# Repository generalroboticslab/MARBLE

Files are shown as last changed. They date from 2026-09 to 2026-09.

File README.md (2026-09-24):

<div align="center">

# MARBLE

**Omnidirectional Amphibious Locomotion via Internal Mass Actuation**

[Niko Weaver](https://github.com/NikoWeaver)\*,
[Boxi Xia](https://boxixia.github.io/)\*,
[Li-Yu Lo](https://pattylo.github.io/)\*,
[Yuhao Huang](https://hyh2001.github.io/),
[Boyuan Chen](https://boyuanchen.com)

\* equal contribution

General Robotics Lab, Duke University

**[Paper (arXiv)](https://arxiv.org/abs/2609.27358)** &middot;
**[Project page](https://generalroboticslab.com/MARBLE)** &middot;
**[Operations runbook](docs/OPERATIONS.md)** &middot;
**[Setup](docs/SETUP.md)** &middot;
**[Policies](policies/README.md)**





</div>

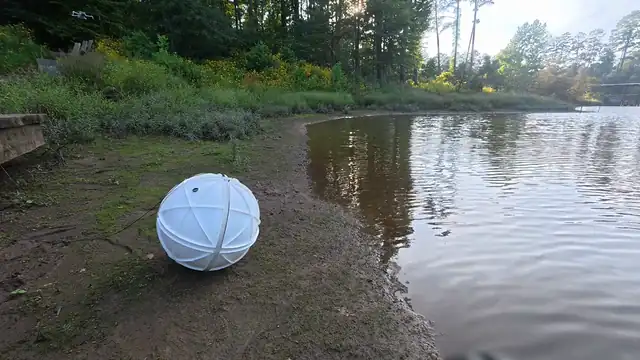
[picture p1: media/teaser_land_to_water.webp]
MARBLE rolling from land into water


<div align="center"><i>Land-to-water entry, real time.</i></div>

MARBLE is a sealed, omnidirectional amphibious robot. Three orthogonal sliders shift internal
masses to roll the spherical shell. The shell is the ground contact, buoyant hull and fin mount,
so one mechanism works on land and water with no reconfiguration.

This repository is the onboard control stack. An Orange Pi runs a 100 Hz loop that reads the
IMU, runs the geometric or learned controller, and sends slider targets over USB serial to a
XIAO nRF52840 CAN bridge driving three GL40 II motors. Bridge firmware, calibration tools and
checkpoints are included, and [`simulation/`](simulation/README.md) trains and replays the deployed
policies in MuJoCo. The code uses the working name `ballbot`.

> **Safety.** Restrain the robot for any first run, and keep a power cutoff within reach: no
> software stop cuts power. `X` latches the E-stop. The controller does not home by default; it
> arms at the pose the drivers report and steps the sliders to centre from it. During `--home`,
> only Ctrl+C stops it. See [safety](docs/OPERATIONS.md#safety),
> [homing](docs/OPERATIONS.md#homing) and [automatic stops](docs/OPERATIONS.md#automatic-stops).

## MARBLE on hardware

<table>
<tr>
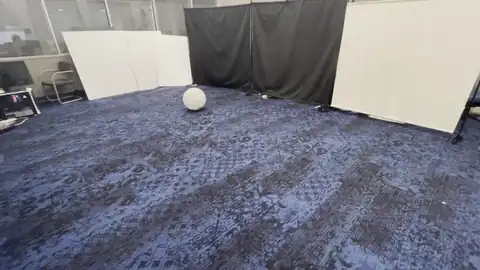
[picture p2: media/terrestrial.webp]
Terrestrial rolling
<td width="33%"></td>
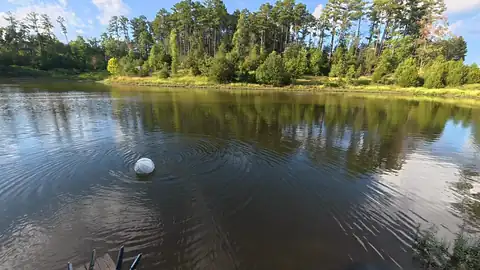
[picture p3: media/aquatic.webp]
Water-surface propulsion
<td width="33%"></td>
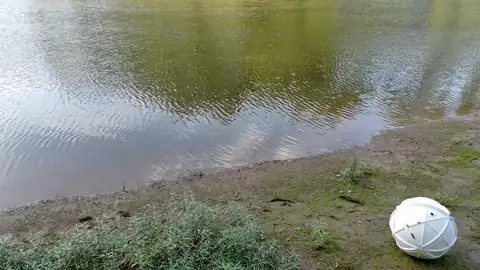
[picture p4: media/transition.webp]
Land-water transition
<td width="33%"></td>
</tr>
<tr>
<td><b>Terrestrial rolling, 1.5x speed.</b> The shell is the ground contact.</td>
<td><b>Water-surface propulsion, 2x speed.</b> Passive fins turn shell rotation into thrust.</td>
<td><b>Land-water transition, 3x speed.</b> One run, no change to the robot.</td>
</tr>
</table>

Planar trajectories of the paper's representative trials (Fig. 4). Colour is time, the circle
marks the start and the cross the end.

<table>
<tr>
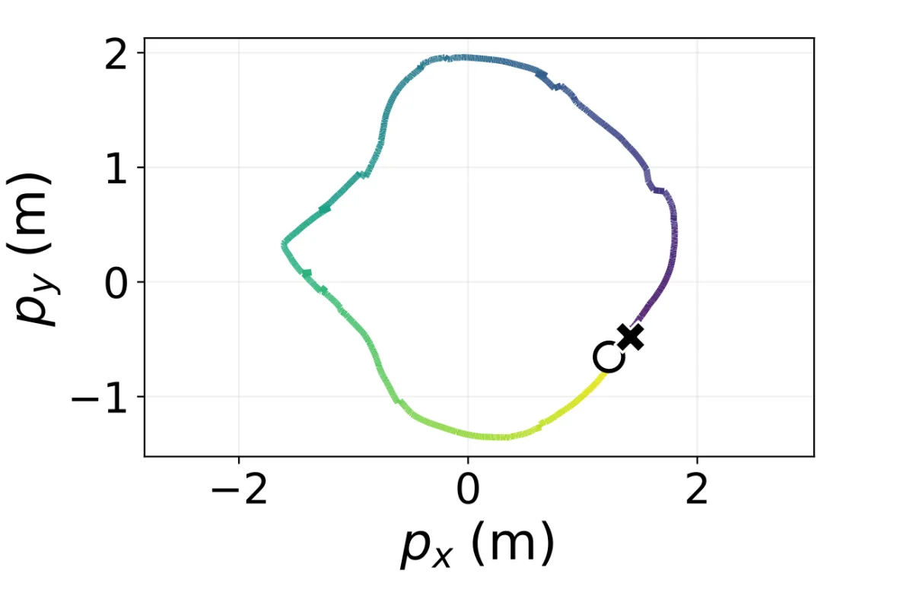
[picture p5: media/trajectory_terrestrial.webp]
Terrestrial trajectory
<td width="33%"></td>
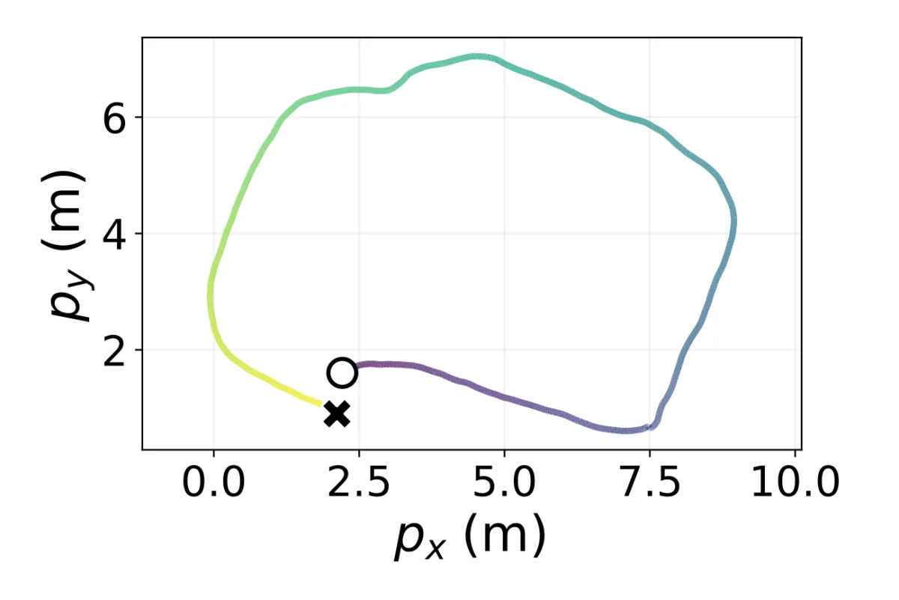
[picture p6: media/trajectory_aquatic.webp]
Aquatic trajectory
<td width="33%"></td>
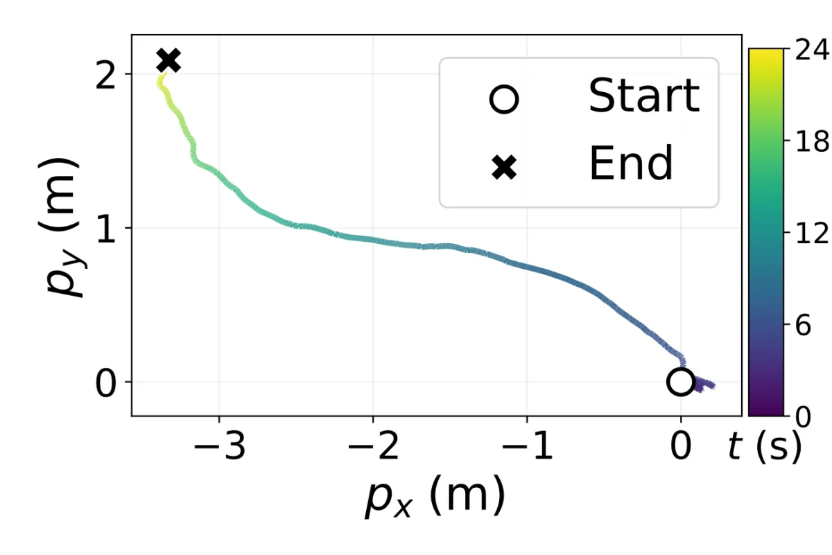
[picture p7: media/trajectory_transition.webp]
Transition trajectory
<td width="33%"></td>
</tr>
</table>

| | Terrestrial | Aquatic | Transition |
| --- | ---: | ---: | ---: |
| Distance | 10.60 m | 5.24 m | 5.21 m |
| Duration | 14.00 s | 14.00 s | 23.93 s |
| Mean speed | 0.745 ± 0.163 m/s | 0.375 ± 0.059 m/s | 0.215 ± 0.146 m/s |
| Max speed | 1.025 m/s | 0.488 m/s | 0.840 m/s |

The aquatic figures cover a 14 s window taken mid-trial, not the whole run.

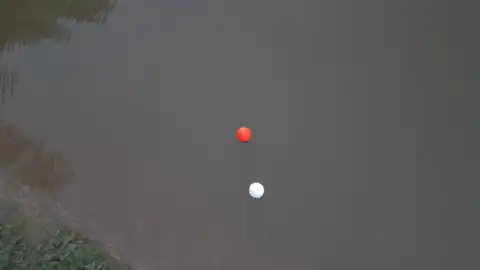
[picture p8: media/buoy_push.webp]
Obstacle interaction with a buoy, aerial view


**Obstacle interaction, aerial view, 4x speed.**

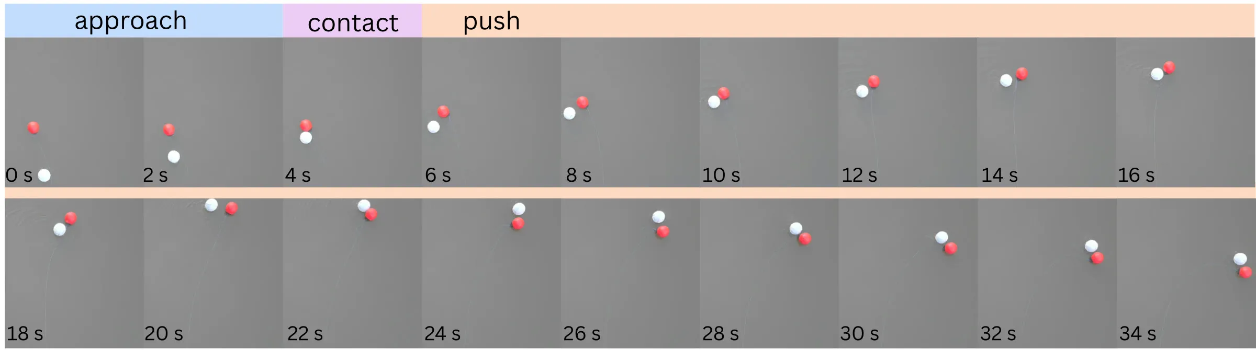
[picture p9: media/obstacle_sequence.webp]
Obstacle interaction time-lapse: approach, contact, push


Fig. 6 time-lapse, 0 to 34 s: approach, shell contact, continued pushing. MARBLE is white, the
buoy red.

## Locomotion and controllers

Locomotion principle

Moving the slider masses offsets the centre of gravity from the shell centre, and the moment
about the ground contact rolls the shell. The sliders rotate with the shell, so both controllers
read the IMU orientation every step.

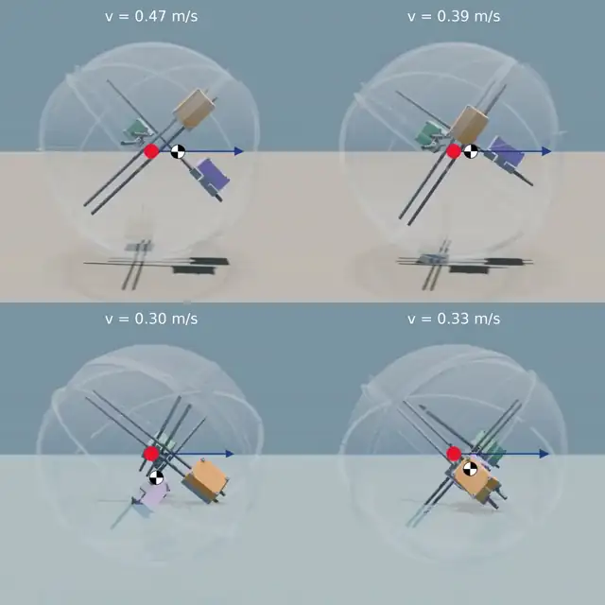
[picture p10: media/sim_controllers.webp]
Geometric and learned controllers in simulation, on ground and on water


MuJoCo rollouts at a commanded 0.5 m/s, real time. Rows: ground, water. Columns: geometric,
learned. The sliding masses have one colour per rail; the quartered circle is their centre of
gravity, the red dot the shell centre and the blue arrow the heading.

| Paper | Code | How to run it |
| --- | --- | --- |
| Geometric controller | `HeuristicPolicy` in [`src/ballbot_runtime.py`](src/ballbot_runtime.py) | `--policy heuristic` (`run.sh` option 4) |
| Learned controller | `TrainedPolicy` in [`src/ballbot_runtime.py`](src/ballbot_runtime.py) | `--policy trained --policy-path policies/<name>/policy_deployed.pt` (`run.sh` option 5) |

The geometric controller computes slider targets from the IMU orientation on every 100 Hz tick.
The learned controller is a 50 Hz TorchScript policy that maps the last three 23-value
observation frames to three slider targets.

The paper compares both controllers on hardware under operator velocity commands in every
direction (Fig. 5). Velocities come from differentiated camera trajectories, drawn from a
common origin with the same axes and colour scale in both panels.

<table>
<tr>
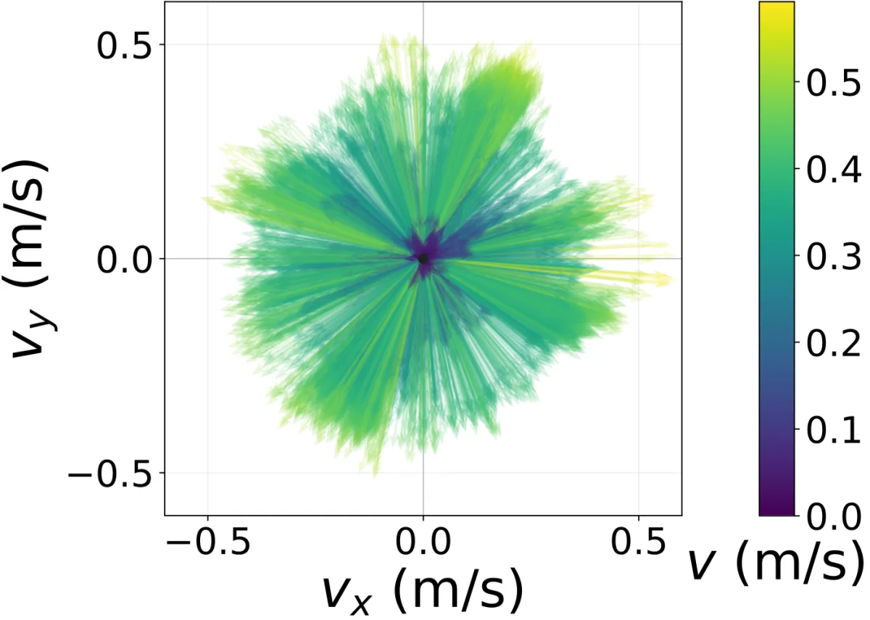
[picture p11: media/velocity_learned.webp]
Measured velocity vectors, learned controller
<td width="50%"></td>
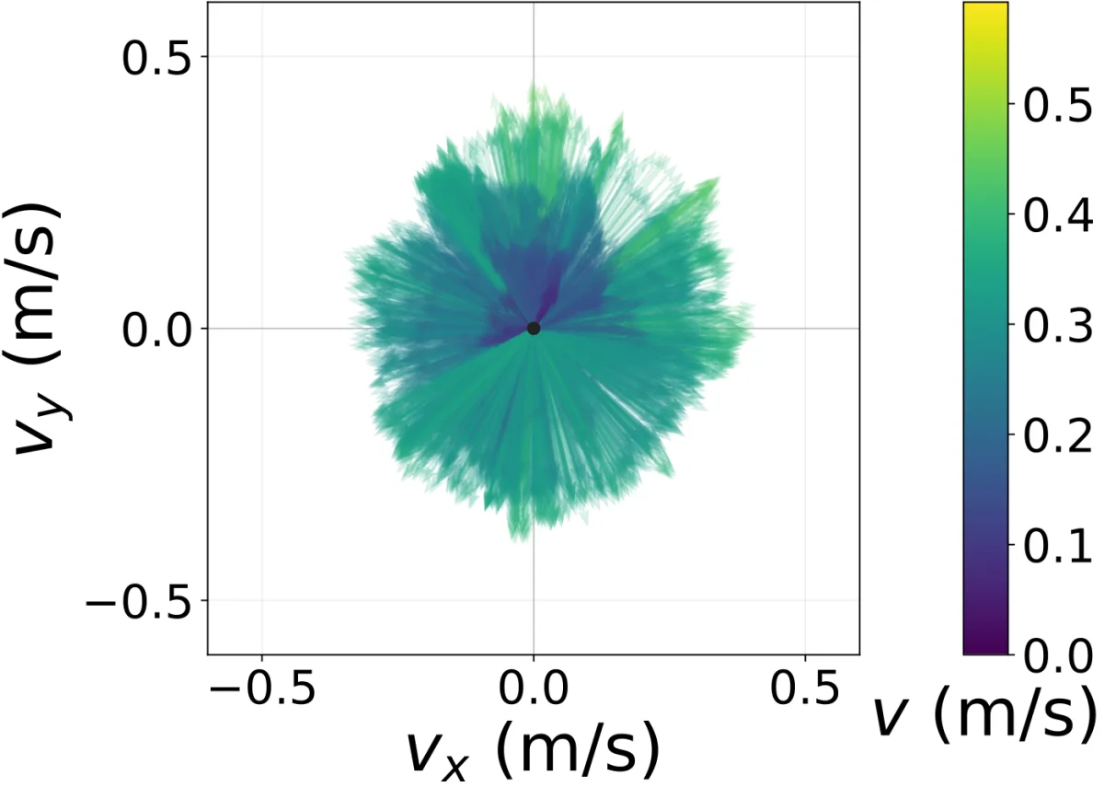
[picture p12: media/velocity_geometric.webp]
Measured velocity vectors, geometric controller
<td width="50%"></td>
</tr>
<tr>
<td><b>Learned controller.</b></td>
<td><b>Geometric controller.</b></td>
</tr>
</table>

| | Learned | Geometric |
| --- | ---: | ---: |
| Mean speed | 0.348 ± 0.114 m/s | 0.252 ± 0.088 m/s |
| Max speed | 0.592 m/s | 0.461 m/s |
| Distance covered | 94.10 m | 63.67 m |
| Duration | 270.37 s | 252.20 s |
| Velocity samples | 7,568 | 7,568 |

## Hardware

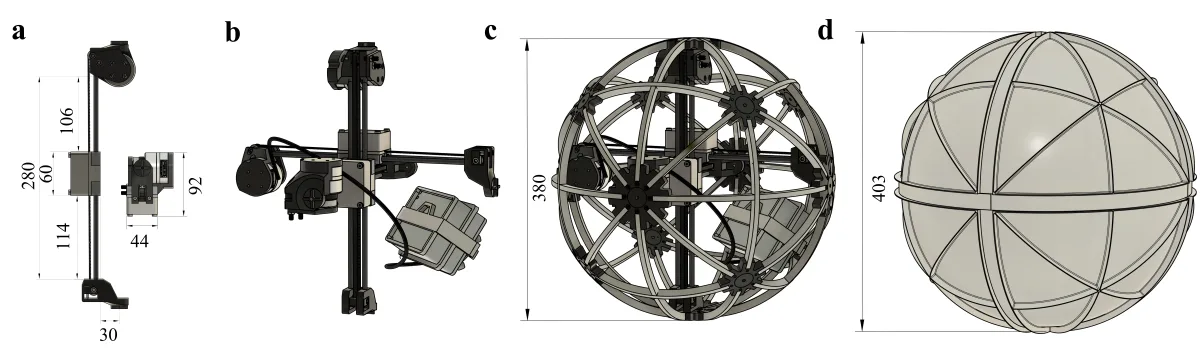
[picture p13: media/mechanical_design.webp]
MARBLE mechanical design


(a) Linear mass-slider module. (b) Three orthogonal sliders and the electronics capsule.
(c) Internal frame without the shell. (d) Complete robot with sealed shell and passive fins.
Dimensions in mm; the 403 mm in (d) is the 387 mm shell plus two 8 mm fins. The full
assembly is in [`cad/MarbleASM.step.zip`](cad/MarbleASM.step.zip) (zipped STEP).

| | |
| --- | --- |
| Outer diameter | 387 mm |
| Shell mass | 1.05 kg |
| Fin height | 8 mm |
| Mass sliders | 3 × 700 g |
| Slider stroke | 220 mm |
| Motors | 3 × CubeMars GL40 II, CAN IDs `0x08`, `0x07`, `0x06`, position-velocity mode |
| Motor bridge | Seeed XIAO nRF52840 Sense + MCP2515; USB serial 115200 baud, CAN 1 Mbit/s |
| IMU | SYD Dynamics TransducerM TM171, USB serial 4 Mbaud, EasyProfile protocol |
| Onboard computer | Orange Pi, aarch64 Linux, Python 3.12 |
| Control rate | 100 Hz; learned policy 50 Hz |
| Battery | 4S LiPo, 16 V |
| Operator input | Keyboard over `ssh -t` |

## System diagram

```
 keyboard over ssh -t                  TM171 IMU, USB serial 4 Mbaud
          |                                        |
          +-------------------+--------------------+
                              v
 Orange Pi   run.sh -> src/ballbot_terminal.py, 100 Hz  -------> logs/*.msgpack
                              |
             HeuristicPolicy (every tick) | TrainedPolicy (50 Hz)
                              | slider targets
             MotorJointMapper: config/calibration.json, clamp 10-195 mm
                              | motor positions
             GLMotorController
                              | USB serial, 115200 baud
 XIAO nRF52840 Sense -> MCP2515 (SPI)
                              | CAN, 1 Mbit/s
          GL40 II 0x08    GL40 II 0x07    GL40 II 0x06
```

## Quick start

```bash
# On the Orange Pi
micromamba create -n py312 python=3.12 -y && micromamba activate py312
export BALLBOT_PYTHON="$(command -v python)"
pip install torch --index-url https://download.pytorch.org/whl/cpu
VCPKG_ROOT=/path/to/vcpkg ./scripts/prepare_orangepi.sh

# Flash xiao_can/xiao_can_bridge/ with motor power off, then
python scripts/verify_xiao_firmware.py

# Over ssh -t, robot restrained: option 3, then option 4 (geometric) or 5 (learned)
./run.sh
```

[`docs/SETUP.md`](docs/SETUP.md) has the details; the committed calibration backup's motor IDs
were remapped, not measured, so run option 3 before the first control run. Read
[`docs/OPERATIONS.md`](docs/OPERATIONS.md) before driving, and always pass `--policy-path` when
launching `src/ballbot_terminal.py` directly: its default points at a retired checkpoint.

To play the deployed policies in simulation instead (desktop with an NVIDIA GPU):

```bash
micromamba create -n marble-sim python=3.12 -y && micromamba activate marble-sim
pip install -r simulation/requirements.txt
cd simulation
python mj_envs/run.py play --task BallbotVelComplexFlatDRLatency   # land
python mj_envs/run.py play --task BallbotVelRingCageComplexDR      # water
```

The shipped checkpoints in `policies/` load automatically; see
[`simulation/README.md`](simulation/README.md) for viewer keys, training and export.

## Documentation

| File | Covers |
| --- | --- |
| [`docs/OPERATIONS.md`](docs/OPERATIONS.md) | Running the robot: menu, keys, flags, automatic stops, logs |
| [`docs/SETUP.md`](docs/SETUP.md) | Install, build, serial ports, flashing, calibration |
| [`docs/validation.md`](docs/validation.md) | Bring-up checklist for a new or rebuilt robot |
| [`docs/DEVELOPING.md`](docs/DEVELOPING.md) | Code map, controller interfaces, observation layout, offline checks |
| [`docs/FLASH_XIAO.md`](docs/FLASH_XIAO.md) | Flashing the bridge firmware |
| [`policies/README.md`](policies/README.md) | Checkpoint catalogue |
| [`simulation/README.md`](simulation/README.md) | Training and playing the policies in simulation |
| [`hardware_bindings/README.md`](hardware_bindings/README.md) | IMU binding |
| [`PROVENANCE.md`](PROVENANCE.md) | Release sources, removed material, third-party code |

## Repository

```
run.sh               operator menu
src/                 control loop, controllers, motor mapping
xiao_can/            GL40 II driver and bridge firmware
hardware_bindings/   C++/nanobind IMU binding
scripts/             calibration, homing, bring-up, offline checks
config/              Python requirements, calibration backup
policies/            TorchScript checkpoints
simulation/          MuJoCo training and playback of the deployed policies
cad/                 STEP assembly of the robot (zipped)
docs/                runbook, setup, developer guide, checklist
media/               figures and clips in this README
CMakeLists.txt       IMU binding build
```

## Provenance and licence

This is a fresh-history release; [`PROVENANCE.md`](PROVENANCE.md) records its sources. The code
is licensed under Apache-2.0 ([`LICENSE`](LICENSE)). The EasyProfile SDK under
`hardware_bindings/imu/EasyProfile/` is BSD-2-Clause; see its
[`NOTICE.md`](hardware_bindings/imu/EasyProfile/NOTICE.md).

## Citation

```bibtex
@misc{weaver2026omnidirectionalamphibiouslocomotion,
      title={Omnidirectional Amphibious Locomotion via Internal Mass Actuation},
      author={Niko Weaver and Boxi Xia and Li-Yu Lo and Yuhao Huang and Boyuan Chen},
      year={2026},
      eprint={2609.27358},
      archivePrefix={arXiv},
      primaryClass={cs.RO},
      url={https://arxiv.org/abs/2609.27358},
}
```

## Acknowledgements

This work was conducted at the General Robotics Lab, Duke University. This work is supported by
DARPA FoundSci program under award HR00112490372, DARPA TIAMAT program under award
HR00112490419, ARO under award W911NF2410405, ARL STRONG program under awards W911NF2320182,
W911NF2220113, and W911NF242021.

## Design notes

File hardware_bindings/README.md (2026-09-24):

# hardware_bindings

The C++ driver for the SYD Dynamics TM171 IMU, exposed to Python through nanobind.

```python
from hardware_bindings.imu.py_imu import IMU
```

The motors do not use this package; they use
[`xiao_can/xiao_gl_motor.py`](../xiao_can/xiao_gl_motor.py).

## Contents

| Path | Contents |
|---|---|
| `imu/imu.hpp`, `imu/imu_nanobind.cpp` | The driver and its nanobind module, `imu_nanobind`. |
| `imu/py_imu.py` | The Python wrapper, `IMU`. Loads `imu_nanobind.abi3.so` from its own directory. |
| `imu/EasyProfile/` | The vendor's protocol SDK, BSD-2-Clause. Ship [`NOTICE.md`](imu/EasyProfile/NOTICE.md) with any binary build. |
| `common/publisher.py` | Socket publisher used by the live viewer. |
| `CMakeLists.txt`, `imu/CMakeLists.txt` | Build rules. |
| `pyproject.toml` | Packaging metadata for use from another project. |

## Building

Build from the repository root with
[`scripts/prepare_orangepi.sh`](../scripts/prepare_orangepi.sh) (see
[`docs/SETUP.md`](../docs/SETUP.md)). It writes `imu_nanobind.abi3.so` and a
copy of `libnanobind-abi3.so` into `imu/`. Before the build, importing
`py_imu` raises `FileNotFoundError` naming the missing `.so`.

The control stack needs no install step. From another project, build first,
then `pip install -e hardware_bindings` (editable, so `libnanobind-abi3.so` is
found).

## The `IMU` class

`IMU(port_name=None)` opens the port at 4,000,000 baud (autodetected when
`None`, see [`docs/SETUP.md`](../docs/SETUP.md#serial-ports)) and starts reading.

| Attribute | Meaning |
|---|---|
| `counter` | Increments with each parsed sample. If it stalls for 5 s, the terminal disables the motors and exits. |
| `rotation_matrix` | 3x3 sensor orientation in the IMU's world frame. |
| `ang_vel` | Body rate in the sensor frame, rad/s. |

The other properties are bound in [`imu/imu_nanobind.cpp`](imu/imu_nanobind.cpp).
`shutdown()` closes the port. `ImuState.from_device` converts the IMU readings
into the controllers' frame; see
[`docs/DEVELOPING.md`](../docs/DEVELOPING.md#units-and-frames).

## Live viewer

```bash
python hardware_bindings/imu/py_imu.py
```

Serves a 3D view with live plots on port 8080 (viser) and publishes each sample
as msgpack over UDP to `localhost:9870`. Needs the built extension plus `viser`,
`scipy`, `orjson` and `msgpack` (all in `config/requirements-robot.txt`).

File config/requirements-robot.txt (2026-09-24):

nanobind
numpy
pyserial
pyyaml
tqdm
msgpack  # run logs written by src/ballbot_terminal.py, read by scripts/analyze_policy_log.py
tyro  # command-line interface of src/ballbot_terminal.py
scipy  # scripts/calibrate_imu.py --viz and --capture-upright
viser  # live 3D view: scripts/calibrate_imu.py --viz (run.sh option 2)
mujoco  # scripts/policy_sim_check.py (offline check)
orjson  # hardware_bindings/common/publisher.py, used by the py_imu.py stand-alone viewer

# PyTorch is not listed: install a CPU build for your platform separately.
# Only trained policies need it (--policy trained, --preflight, policy_sim_check.py).

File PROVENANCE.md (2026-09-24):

# Provenance

This repository is a fresh-history public release, assembled from two internal
General Robotics Lab repositories by copying cleaned file trees. The internal
history is not published.

## Sources

| Directory here | Internal repository | Branch | Commit |
|---|---|---|---|
| everything except `hardware_bindings/`, `simulation/`, `media/` and `cad/` | ballbot_control | `CAN_rework` | `401d29a14e05e3287c25f97f9496d889925c85c2` |
| `hardware_bindings/` | hardware_bindings | `ballbot` | `06d9f5e581b3dbc43382254591f45bf441aef403` |
| `simulation/` | legged_env_v2 (training) | `master` | generated by its `scripts/make_marble_sim.py` |

The documentation, `LICENSE`, `CITATION.cff`, `.gitattributes`, this file and
the EasyProfile `NOTICE.md` are new. Kept files lost commented-out code and
unused functions; apart from the removals below, control behaviour is
unchanged.

`hardware_bindings/` inlines only the IMU extension of a private submodule
shared by several lab robots, with unused code (`FakeIMU`, a getter, the NNG
publisher classes) removed and the build files cut to match.
`imu/EasyProfile/` is byte-identical to the internal copy.

`cad/MarbleASM.step.zip` is the robot's CAD assembly as STEP. It
includes vendor models of purchased parts (GL40 II motors, the XIAO board and
its CAN breakout, electronics, fasteners); those keep their vendors' terms.

## Removed

| Removed | Reason |
|---|---|
| `deprecated/` | Superseded entry points and experiments |
| `gs_usb/` | Retired SocketCAN path, replaced by `xiao_can/` |
| `camera/` | Optional camera pipeline, not in this stack |
| `handoff.md`, `camera/handoff.md` | Internal notes |
| `visualization/` | Overhead-video trajectory tools and one run's data; not part of the control stack |
| `hardware_bindings/motor/`, `hardware_bindings/ft_servo/` | Drivers for another robot |
| `hardware_bindings/imu/test_dual_imu.py` | Two-IMU rig; MARBLE has one |
| `scripts/rehome_sliders.py`, `scripts/rehome_interactive.py` | Superseded by `scripts/rehome_auto.py` |
| `scripts/enable_motor_5_only.py` | One-off for retired motor IDs |
| `scripts/test_control_timing.py` | Tested a scheduler that no longer exists |
| `scripts/test_sine_log.py` | One-off bench script |
| `scripts/convert_gains.py` | Its default geometry was wrong |
| `xiao_can/xiao_can_bridge/XboxBluefruitClient.h` | Never compiled into the firmware |
| `src/xbox_controller.py` and `--xbox` | Xbox input dropped; the keyboard drives |
| `config/startupcommands.txt` | Stale copy of [`docs/SETUP.md`](docs/SETUP.md) |
| `docs/TRAINED_POLICY_GUIDE.md` | Stale; replaced by [`docs/DEVELOPING.md`](docs/DEVELOPING.md) |
| `policies/BallbotVelRingCageFlatDRLatency/meshes` | Symlink into the training asset tree |
| `.vscode/settings.json` | Editor settings, not source |
| `logs/` | Recorded runs (four msgpack logs and plots) |
| `.gitmodules` | Submodule pointer; source now inlined |

## Motor IDs

The release uses CAN IDs `0x08`, `0x07` and `0x06` (`MOTOR_IDS` in
`src/ballbot_runtime.py`), and the bridge firmware matches
([`docs/FLASH_XIAO.md`](docs/FLASH_XIAO.md)).

`config/calibration.robot-backup.json` was recorded on the old ID set (`0x03`,
`0x04`, `0x06`); its IDs were rewritten to `0x08`, `0x07`, `0x06` in
`JOINT_NAMES` order with the signs carried over, so it may not match a robot's
wiring. Calibrate before the first control run
([`docs/SETUP.md`](docs/SETUP.md#slider-calibration)).

## The shipped checkpoints

The six `policy_deployed.pt` archives are the internal copies with
TorchScript's `*.debug_pkl` entries (training-machine paths and source text)
removed. Weights and compiled code are byte-identical and outputs match; the
md5s in [`policies/README.md`](policies/README.md#checksums) differ from the
internal copies.

Each `robot.xml` references meshes from the training asset tree (STL, plus one
OBJ in four of them) and, in those four, `textures/carbon_fiber_plain_spec.png`.
These are not redistributed, so `robot.xml` does not compile in MuJoCo from
this repository. The runtime reads only `env_config.yaml`;
`scripts/policy_sim_check.py` needs the meshes and texture. The wire mesh is
referenced as `meshes/wire_1_Body1.stl`, which differs from its file name in
the training asset tree; rename that file to match.

## Third-party components

Only EasyProfile is redistributed; everything else is fetched at setup under
its own licence. Versions are unpinned except the two Arduino packages in
[`docs/FLASH_XIAO.md`](docs/FLASH_XIAO.md).

| Component | Use | Source | Licence |
|---|---|---|---|
| SYD Dynamics EasyProfile 1.1.9 (R) | IMU serial protocol; code adapted into `hardware_bindings/imu/imu.hpp` | `hardware_bindings/imu/EasyProfile/` | BSD-2-Clause; see [`NOTICE.md`](hardware_bindings/imu/EasyProfile/NOTICE.md) |
| nanobind | Python binding of the IMU driver | pip | BSD-3-Clause |
| Eigen3 | Linear algebra in the IMU driver | vcpkg | MPL-2.0 |
| CSerialPort (itas109) | Serial port in the IMU driver | vcpkg | LGPL-3.0 with a linking exception |
| fmt | Linked into the IMU extension | vcpkg | MIT |
| Seeed nRF52 Boards (`Seeeduino:nrf52`) | Board package for the XIAO bridge firmware | Seeed Arduino board index | LGPL-2.1-or-later; not redistributed |
| `mcp_canbus` (Longan Labs) | MCP2515 driver in the firmware | https://github.com/Longan-Labs/Arduino_CAN_BUS_MCP2515 | MIT |
| Python packages | Runtime, tools, offline checks | PyPI: `config/requirements-robot.txt` | Each its own |
| PyTorch | Running trained policies | Installed separately | BSD-3-Clause, plus bundled components |

## Media

`media/` holds figures and clips from the project page
(https://generalroboticslab.com/MARBLE), re-encoded as WebP.

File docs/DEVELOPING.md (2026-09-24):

# Developing

Run the examples from the repository root.

## Code map

| Path | Contents |
|---|---|
| `src/ballbot_runtime.py` | Constants, calibration, joint-to-motor mapper, IMU frame, both controllers, policy contract check. No hardware I/O; imports only `numpy` at load. |
| `src/ballbot_terminal.py` | `BallbotController`: 100 Hz loop, keyboard, arming, homing, safety, logging. Also the CLI. |
| `xiao_can/xiao_gl_motor.py` | `GLMotorController`: GL40 motors through the XIAO serial-to-CAN bridge. |
| `xiao_can/xiao_can_bridge/` | Bridge firmware. Host sends `S:<id>:<length>:<data>` (hex); bridge returns `R:` lines; `V` returns the version string. |
| `hardware_bindings/imu/py_imu.py` | `IMU` driver ([README](../hardware_bindings/README.md)). |
| `scripts/` | Calibration, bench tools, [offline checks](#offline-checks). |

## Units and frames

**Joints.** Every three-element array (observation, action, target) is in
`JOINT_NAMES` order: `base_link_Slider-5`, `base_link_Slider-6`,
`base_link_Slider-7`. A joint position is metres from the 114 mm idle position
(`IDLE_POSITION_MM`) on 220 mm of travel (`MAX_TRAVEL_MM`). Positive motion
moves the mass toward base −Z, +Y and −X respectively (`JOINT_POSITIVE_AXIS`).

**Motors.** Motor positions are radians, in `MOTOR_IDS` order `0x08`, `0x07`,
`0x06`. One turn is 100 mm (`MM_PER_TURN`). After homing, 0 rad is the 0 mm
hardstop. `MotorJointMapper` converts using `config/calibration.json`.

**Calibration file.** `schema_version` 2. Per joint: `motor_id` (8, 7 or 6,
each once), `encoder_sign` and `joint_to_travel_sign` (each ±1). The loader
rejects any other schema version and any mapping that does not cover every
joint and motor exactly once. The procedure is in
[`SETUP.md`](SETUP.md#slider-calibration).

**Orientation.** `ImuState` holds `rotation_world_base` (R_wb) and
`angular_velocity_world` (rad/s). `ImuState.from_device(imu)` computes
R_wb = R_ws R_bs^T and ω_world = R_ws ω_sensor, with R_bs the IMU mounting
rotation (`R_BASE_SENSOR`). It raises `ValueError` on non-finite or
non-orthonormal data.

**Command frame.** Commands are in world XY. `with_yaw_reference(yaw)` rotates
the world frame about +Z so command +X points at `yaw`, leaving roll and pitch
unchanged. The terminal sets it from `--yaw-offset-deg` and Q/E.

**Travel limits.**

| Stage | Limit |
|---|---|
| `HeuristicPolicy.act` | −0.104 to +0.096 m (`HEURISTIC_LOWER_M`, `HEURISTIC_UPPER_M`) |
| `TrainedPolicy.act_from_frame` | −0.114 to +0.106 m (`JOINT_LOWER_M`, `JOINT_UPPER_M`) |
| `MotorJointMapper`, every target | Joint clipped to −0.114/+0.106 m, then travel to 10–195 mm (`SAFE_MIN_TRAVEL_MM`, `SAFE_MAX_TRAVEL_MM`) |

Reach from the 114 mm centre is asymmetric (104 mm down, 81 mm up);
`joint_to_travel_sign` sets which side is short.

## Runtime API

### Geometric controller

```python
import sys
from pathlib import Path

import numpy as np

sys.path.insert(0, "src")
from ballbot_runtime import HeuristicPolicy, ImuState, MotorJointMapper, SliderCalibration

# The robot uses config/calibration.json; the backup runs on a fresh clone.
cal = SliderCalibration.load(Path("config/calibration.robot-backup.json"))
mapper = MotorJointMapper(cal)

policy = HeuristicPolicy()

# Upright and at rest. On the robot this comes from ImuState.from_device(imu).
imu_state = ImuState(rotation_world_base=np.eye(3), angular_velocity_world=np.zeros(3))

direction_xy = np.array([1.0, 0.0])   # toward +X of the command frame
magnitude = 0.5                       # 0 to 1

joint_targets_m = policy.act(direction_xy, magnitude, imu_state, np.zeros(3), np.zeros(3))
motor_targets_rad = mapper.motor_targets_from_joint_position(joint_targets_m)
```

`HeuristicPolicy.act()` places a point 1.5 × magnitude m out along the
direction and sends each slider to the closest point on its rail; the example
returns `[0, 0, -0.104]`.

### Learned policy

```python
import sys
from pathlib import Path

import numpy as np

sys.path.insert(0, "src")
from ballbot_runtime import ImuState, TrainedPolicy

policy = TrainedPolicy(Path("policies/BallbotVelComplexFlatDRLatency/policy_deployed.pt"))

imu_state = ImuState(np.eye(3), np.zeros(3))
joint_pos = np.zeros(3, dtype=np.float32)    # m, from MotorJointMapper.joint_state_from_motors
joint_vel = np.zeros(3, dtype=np.float32)    # m/s
last_action = np.zeros(3, dtype=np.float32)

policy.reset()
for _ in range(5):                           # one call per 50 Hz policy step
    frame = TrainedPolicy.build_frame(
        np.array([0.3, 0.0]),                # commanded velocity in the command frame, m/s
        imu_state, joint_pos, joint_vel, last_action,
    )
    joint_targets_m, last_action = policy.act_from_frame(frame)
```

`TrainedPolicy(policy_path, action_scale=1.0, policy_hz=POLICY_HZ, strict=True)`
loads the model on the CPU, checks the [`env_config.yaml`](#env_configyaml-contract)
beside it, and confirms a finite `(1, 3)` output for a zero input. It raises on
any failure.

- `build_frame(command_world_xy, imu_state, joint_pos, joint_vel, last_action)`
  (static) returns the 23-element [frame](#observation-frame).
- `act_from_frame(frame)` appends to the three-frame history and returns
  `(joint_targets_m, action)`. Pass `action` back as `last_action`.
- `reset(frame=None)` fills the history with copies of `frame`, or zeros.
- `set_action_scale(scale)` sets the runtime scale, clipped to [0, 1].

Call `act_from_frame` once every 20 ms (`POLICY_HZ` = 50). Always pass
`policy_path`: `DEFAULT_POLICY_PATH` names a retired checkpoint
([`OPERATIONS.md`](OPERATIONS.md#learned-policy)).

### Motors

The terminal opens the bridge like this (run with `PYTHONPATH=src:xiao_can`):

```python
from ballbot_runtime import MOTOR_IDS
from xiao_gl_motor import GL40, GL_MODE_POS_VEL, GLMotorController

motor = GLMotorController(
    [[motor_id, "xiao", GL40] for motor_id in MOTOR_IDS],
    control_mode=GL_MODE_POS_VEL,
    default_vel_limit=30.0,   # rad/s; the terminal passes --vel-limit
    port_name=None,           # autodetect; the terminal passes --motor-port
)
```

Arrays are in `MOTOR_IDS` order: write `mech_pos_ref`/`mech_vel_ref`, read
`mech_pos`, `mech_vel`, temperatures, `error_code` and `last_feedback_time`.
`motion_control_once()` sends one command to every motor.

The constructor raises `RuntimeError` unless the bridge reports
`BALLBOT_XIAO_BRIDGE_V3` ([`FLASH_XIAO.md`](FLASH_XIAO.md)) and leaves the
motors disabled. Feedback streams only after `enable()`; follow
`BallbotController.arm()` for a safe start.

`ballbot_runtime.py` has no safety logic. A program that drives the motors
itself gets none of the terminal's
[automatic stops](OPERATIONS.md#automatic-stops) or learned-policy limits.

## Adding a controller

A controller needs one method, called positionally:
`act(direction_world_xy, magnitude, imu_state, joint_pos, joint_vel)`,
returning (3,) float32 slider targets in metres from centre. Inputs are in the
command frame, and `direction_world_xy` is a unit vector.

There is no plug-in hook: replace `self.heuristic = HeuristicPolicy()` in
`BallbotController.__init__` and launch with `--policy heuristic`. The terminal
calls `act()` every 100 Hz tick while a movement command is active and centres
the sliders otherwise. `magnitude` starts at `--heuristic-magnitude`; N/M move
it in 0.1 steps within [0.01, 10.0], so clip it yourself. With smoothing off
(the default), targets go from the mapper clip straight to the drives.

## Exporting a learned policy

The runtime accepts any TorchScript module that meets this contract:

| | |
|---|---|
| Input | float32 `(1, 3, 23)`: three [frames](#observation-frame), oldest first |
| Output | `(1, 3)`, in `JOINT_NAMES` order |
| Output meaning | Clipped to [−1, 1], × 0.106 m (`ACTION_SCALE_M`) × runtime action scale (`--action-scale`, default 1.0), then clipped to −0.114/+0.106 m. An absolute target from centre, not an increment. |
| Rate | 50 Hz (`POLICY_HZ`) |
| Device | CPU: `torch.jit.load(path, map_location="cpu")` |

Save the traced or scripted actor as `policy_deployed.pt`:

```python
import torch

model.eval()
example = torch.zeros((1, 3, 23), dtype=torch.float32)   # (batch, history, frame)
with torch.no_grad():
    traced = torch.jit.trace(model, example)
traced.save("policies/MyPolicy/policy_deployed.pt")
```

Put the `env_config.yaml` exported by training beside it
([contract](#env_configyaml-contract)); a hand-written one checks nothing.
Without `env_config.yaml` the runtime prints a `NOTE` and runs only the shape
check, which cannot catch a wrong action scale or a reordered frame.

Check it, then run it:

```bash
python src/ballbot_terminal.py --preflight --policy-path policies/MyPolicy/policy_deployed.pt
python src/ballbot_terminal.py --policy trained --policy-path policies/MyPolicy/policy_deployed.pt
```

`./run.sh` lists the new folder in options 5 and 6 automatically.

## Observation frame

`TrainedPolicy.build_frame` packs each frame in this order. Terms are named as
in `env_config.yaml`.

| Index | Term | Source | Units |
|---|---|---|---|
| 0-2 | `angular_velocity` | `imu_state.angular_velocity_world` | rad/s, command frame |
| 3-4 | `commands_xy` | commanded velocity; in the terminal, unit direction × `--speed` | m/s, command frame |
| 5-7 | `dofPosition` | `joint_pos` | m from centre |
| 8-10 | `dofVelocity` | `joint_vel` | m/s |
| 11-13 | `actions` | previous `action` from `act_from_frame`, in [−1, 1] | unitless |
| 14-22 | `base_rotation_matrix` | `imu_state.rotation_world_base`, row-major | unitless |

An empty history is filled from the first frame. The terminal feeds back the
raw `action`, so `--action-scale` below 1 and `--target-rate-limit` above 0
change the applied target but not the fed-back action.

## `env_config.yaml` contract

`PolicyDeployConfig` checks these fields against the runtime constants.

| Field | Required value |
|---|---|
| `policy_obs_group` | Observation group to read; `actor` if absent |
| `observation.<group>` term names, in order | `angular_velocity`, `commands_xy`, `dofPosition`, `dofVelocity`, `actions`, `base_rotation_matrix` |
| Sum of `term_dim` | 23 |
| `history_length` of every term | Equal, and 3 |
| `action.dim` | 3 |
| `action_scale` of every `actuators` entry | Equal, and 0.106 |
| `simulation.control_freq` | 50 |
| `simulation.timestep` × `simulation.decimation` | 1 / `control_freq` |

A mismatch raises `RuntimeError` listing every problem. Unequal histories or
action scales raise `ValueError` at load. Other fields are not read.
`strict=False` turns mismatches into warnings; only `policy_sim_check.py` uses
it. The terminal is always strict.

## Offline checks

None of these opens the motors or the IMU.

| Check | Command | Needs |
|---|---|---|
| Readiness | `python scripts/preflight_heuristic.py [--require-calibration]` | `numpy`, `pyserial`; on Linux, Python 3.12 and the built IMU binding |
| Policy contract | `python src/ballbot_terminal.py --preflight --policy-path <pt>` | `torch`, `pyyaml`, `tyro`, `msgpack`, `pyserial` |
| Policy in simulation | `python scripts/policy_sim_check.py --robot-xml <xml> --policy-path <pt>` | `torch`, `pyyaml`, `mujoco`, a `robot.xml` that compiles |
| Run-log analysis | `python scripts/analyze_policy_log.py <log>.msgpack [--radius 0.19]`, or `--self-check` | `numpy`, `msgpack` |

`preflight_heuristic.py` (`./run.sh` option 1, also run by
`prepare_orangepi.sh`) checks the Python version, `pyserial`, controller and
mapper output, the firmware source (text match only), the IMU binding, the
calibration file and script permissions. A missing calibration is a warning
unless `--require-calibration` is passed.

`policy_sim_check.py` runs `TrainedPolicy` in CPU MuJoCo on a ground plane
(water checkpoints too) and reports speed, tracking error and slider speed;
`--help` lists its sweeps. The shipped `robot.xml` files need meshes that are
not included ([known issues](#known-issues)).

## Run logs

Each run log ([`OPERATIONS.md`](OPERATIONS.md#status-line-and-logs)) is
concatenated msgpack objects: one header, then one step per policy step while
a movement command is active.

```python
import msgpack

with open(path, "rb") as f:
    header, *steps = msgpack.Unpacker(f, raw=False)
```

The header records the policy, rate, joint and motor IDs and observation
terms; each step records the frame (`obs`), `action`, `target_m`, motor
feedback and the operator settings. `PolicyRunLogger` in
`src/ballbot_terminal.py` defines every field.

Heuristic runs log `action` as zeros and `target_m` as the controller output.
`obs` is in the command frame, so steps compare only at equal `yaw_ref_deg`.

## Known issues

- `analyze_policy_log.py` stops with `KeyError: 'stiffness'` on current logs,
  which record `kp` and `kd`. Only `--self-check` works; compute the achieved
  rate from `t_s`.
- The achieved policy rate is not checked.
- The `policies/*/robot.xml` files do not compile as shipped
  ([`PROVENANCE.md`](../PROVENANCE.md#the-shipped-checkpoints)).

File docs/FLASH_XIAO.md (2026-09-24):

# Flashing the XIAO CAN bridge

The firmware in `xiao_can/xiao_can_bridge/` relays CAN at 1 Mbit/s to and from
USB serial. At boot it sends clear-fault and then disable to motors `0x08`,
`0x07` and `0x06`. The motor driver refuses to run unless the bridge reports
`BALLBOT_XIAO_BRIDGE_V3`.

> [!WARNING]
> Keep motor power off until step 5 passes.

You need a USB-C data cable and a computer with this repository.

## 1. Install arduino-cli and the board package

```bash
brew install arduino-cli                                                                 # macOS
curl -fsSL https://raw.githubusercontent.com/arduino/arduino-cli/master/install.sh | sh  # Linux
```

```bash
arduino-cli config init --overwrite
arduino-cli config add board_manager.additional_urls \
  https://files.seeedstudio.com/arduino/package_seeeduino_boards_index.json
arduino-cli core update-index
arduino-cli core install Seeeduino:nrf52@1.1.10
```

1.1.9 or later works; earlier releases lack the Sense Plus board.

## 2. Install the CAN library

```bash
arduino-cli lib install mcp_canbus@1.0.0
```

If the index is unavailable, place
<https://github.com/Longan-Labs/Arduino_CAN_BUS_MCP2515> in
`~/Documents/Arduino/libraries/` (macOS) or `~/Arduino/libraries/` (Linux).

## 3. Find the port

```bash
arduino-cli board list
```

The XIAO shows up as, for example, `/dev/cu.usbmodem14201` (macOS) or
`/dev/ttyACM0` (Linux); this is `<PORT>` below. If it is missing, double-tap
RESET: the bootloader appears as a drive named `XIAO-SENSE`.

## 4. Compile and upload

From the repository root:

```bash
arduino-cli compile --fqbn Seeeduino:nrf52:xiaonRF52840SensePlus xiao_can/xiao_can_bridge
arduino-cli upload --fqbn Seeeduino:nrf52:xiaonRF52840SensePlus --port <PORT> xiao_can/xiao_can_bridge
```

Use this FQBN for a plain Sense too; the pins used (D7 chip select, SPI on D8
to D10, RGB LED) map identically.
In the Arduino IDE, the board is Tools > Board > Seeed nRF52 Boards > Seeed
XIAO nRF52840 Sense Plus.

## 5. Verify

With motor power still off (needs `pyserial` and `numpy`):

```bash
python scripts/verify_xiao_firmware.py        # add --motor-port <PORT> if autodetect fails
```

Expected: `PASS: bridge reports BALLBOT_XIAO_BRIDGE_V3. Firmware is up to date.`

| Message | Meaning |
|---|---|
| `FAIL: expected BALLBOT_XIAO_BRIDGE_V3, bridge said: ...BRIDGE_V2` | The upload did not take. Repeat step 4. |
| `XIAO bridge firmware is outdated; flash BALLBOT_XIAO_BRIDGE_V3` at robot start | This procedure was not done. |

LED: blue while starting, green once CAN is up, repeating double red blink if
the MCP2515 failed to initialise (check the SPI wiring and the CAN board's
power).

Put the XIAO back if you removed it, then reconnect motor power.

The motor IDs in `motors[]` in `xiao_can_bridge.ino` must match `MOTOR_IDS` in
`src/ballbot_runtime.py`. Change both together.

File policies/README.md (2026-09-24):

# Policy checkpoints

The six TorchScript velocity policies for `--policy trained`. Launch them as in
[`docs/OPERATIONS.md`](../docs/OPERATIONS.md#learned-policy); the export
contract is in [`docs/DEVELOPING.md`](../docs/DEVELOPING.md#exporting-a-learned-policy).

## Which one to run

| Folder | Medium | Use |
|---|---|---|
| `BallbotVelComplexFlatDRLatency` | land | Default on land. `run.sh` preselects it. |
| `BallbotVelRingCageComplexDR` | water | Default on water. |
| `BallbotVelRingCageComplexSmooth` | water | Only if the water default visibly chatters. |
| `BallbotVelComplexFlatSmooth` | land | Not for use: too slow on hardware. |
| `BallbotVelRingCageFlatDRLatency` | land | Retired. A/B comparison only. |
| `BallbotVelRingCageShellDR` | water | Retired. A/B comparison only. The code default `DEFAULT_POLICY_PATH` still names it. |

Folder names are training-task names and do not always match the medium:
`BallbotVelRingCageFlatDRLatency` is a land policy.

## How they differ

**Defaults.** Their `env_config.yaml` files are identical except for the initial
root height: 0.194 m on land, 1.092 m in the water scene. The water `robot.xml`
adds 13 ring geoms (`ring_torus_*`) around the shell.

**Smooth siblings.** Each `Smooth` folder is its parent retrained with a heavier
action-rate penalty (-0.6 on land, -0.35 on water, against -0.2); the files are
otherwise identical to the parent's.

**Retired.** The two retired checkpoints were trained on an earlier plant whose
slider servo (kp 250, kd 50) behaved like the software trajectory smoother, so
they must run with it on
([`docs/OPERATIONS.md`](../docs/OPERATIONS.md#trajectory-smoothing)); their
`requires_smoothing` file tells `run.sh`. The current plant (motor gains,
effort limit, armature) is in the `actuators` block of each `env_config.yaml`.
Its rail friction (0.2 N) is well below the real breakaway force (roughly a
slider's 6.9 N weight, unmeasured).

## Folder contents

| File | Read by | Contents |
|---|---|---|
| `policy_deployed.pt` | `TrainedPolicy` | TorchScript actor, CPU. Input `(1, 3, 23)` float32, output `(1, 3)`. |
| `env_config.yaml` | `PolicyDeployConfig` | A few fields are checked at startup. The rest records the training plant. |
| `robot.xml` | `scripts/policy_sim_check.py` only | Exported MuJoCo model. Does not compile as shipped; see [`PROVENANCE.md`](../PROVENANCE.md#the-shipped-checkpoints). |
| `requires_smoothing` | `run.sh` | Retired folders only. |

## Checksums

MD5 of each `policy_deployed.pt` as shipped:

| Folder | md5 |
|---|---|
| `BallbotVelComplexFlatDRLatency` | `30a67996e22d30d22799227220704c29` |
| `BallbotVelComplexFlatSmooth` | `42ff6e060d421063a629479725128d08` |
| `BallbotVelRingCageComplexDR` | `3e25e90b2496beff642e8ad691035eb0` |
| `BallbotVelRingCageComplexSmooth` | `ad85b4aa03b7abe5c9bb7960b2d4da62` |
| `BallbotVelRingCageFlatDRLatency` | `2b3744860dfa68e3895dd0a25ab385fc` |
| `BallbotVelRingCageShellDR` | `de4482461c2c5a569682f6172df1da0c` |

```bash
md5sum policies/*/policy_deployed.pt   # Linux
md5 policies/*/policy_deployed.pt      # macOS
```

## Adding a checkpoint

Put `policy_deployed.pt` and its `env_config.yaml` in `policies/<name>/` and
check it as in [`docs/DEVELOPING.md`](../docs/DEVELOPING.md#exporting-a-learned-policy).
`run.sh` lists it automatically.

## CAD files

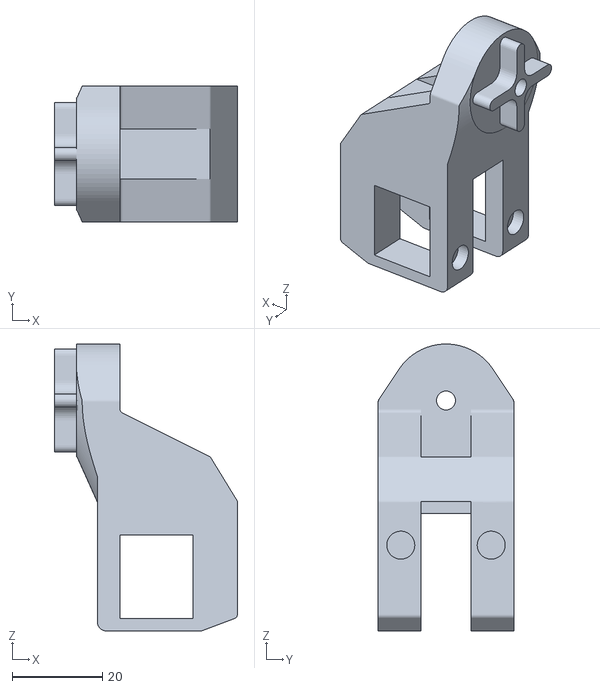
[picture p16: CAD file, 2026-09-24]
simulation/asset/ball_linear_complex/meshes/NoWeightBelt_1_BeltIdler_1_MainBody_1_MainBody.stl
40.5 x 30.0 x 63.5

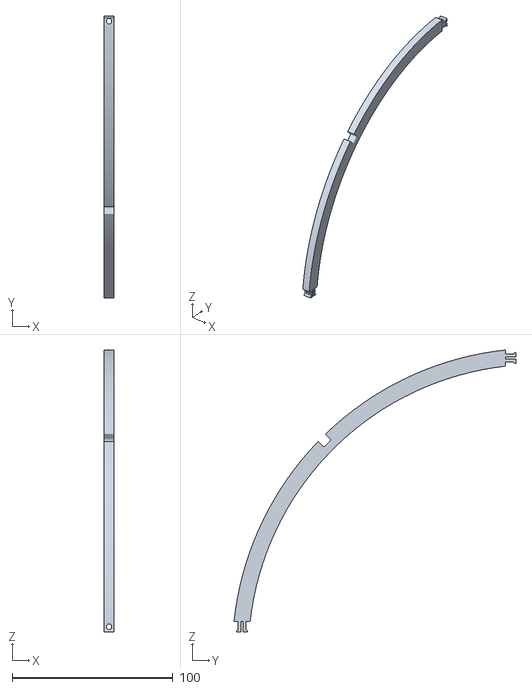
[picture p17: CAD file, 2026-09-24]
simulation/asset/ball_linear_complex/meshes/V2Frame_1_Main_Beam_V2_1_Body1.stl
6.35 x 175.4 x 175.4

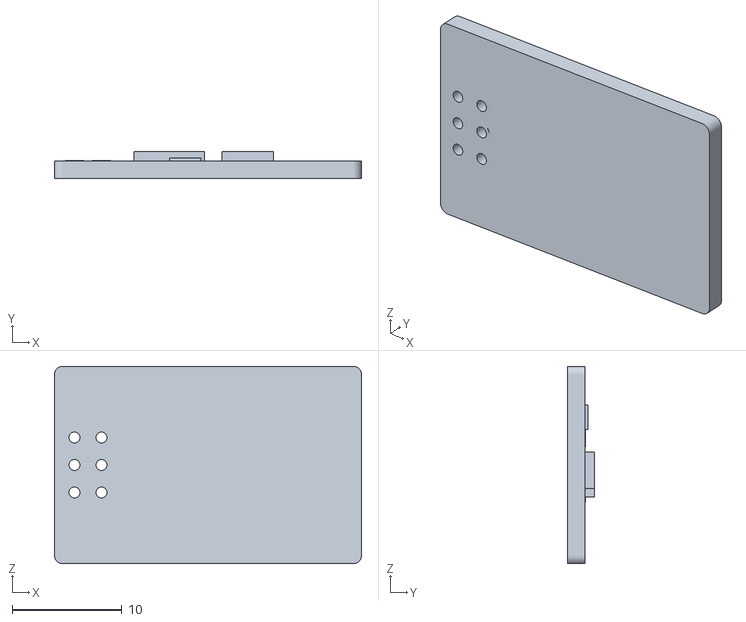
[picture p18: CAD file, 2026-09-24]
simulation/asset/ball_linear_complex/meshes/CapsuleHolder_1_Singular_Capsule_1_CAN_Bus_Breakout_Board_for_Seeed_Studio_XIAO_v1_1_Body1.stl
28.0 x 2.46 x 18.0

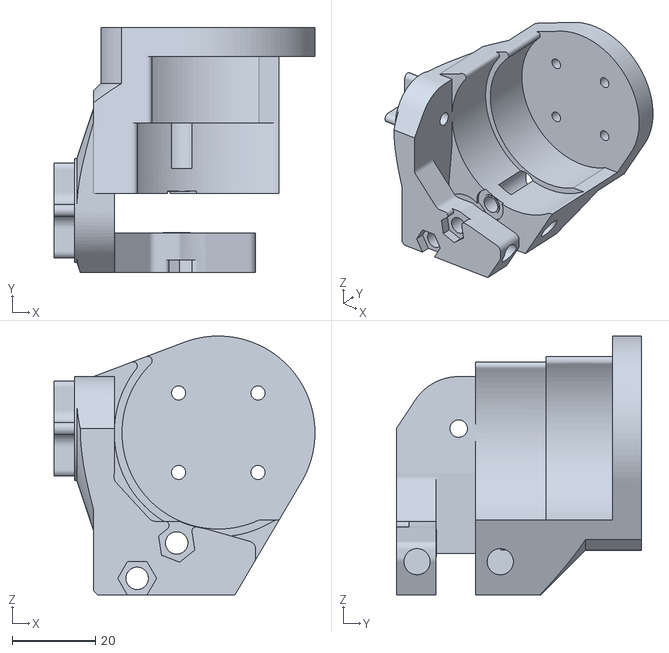
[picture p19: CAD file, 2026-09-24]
simulation/asset/ball_linear_complex/meshes/NoWeightBelt_1_BeltDrivenMotorHolder_27mmOffset_1_Body1.stl
62.7 x 59.0 x 62.2

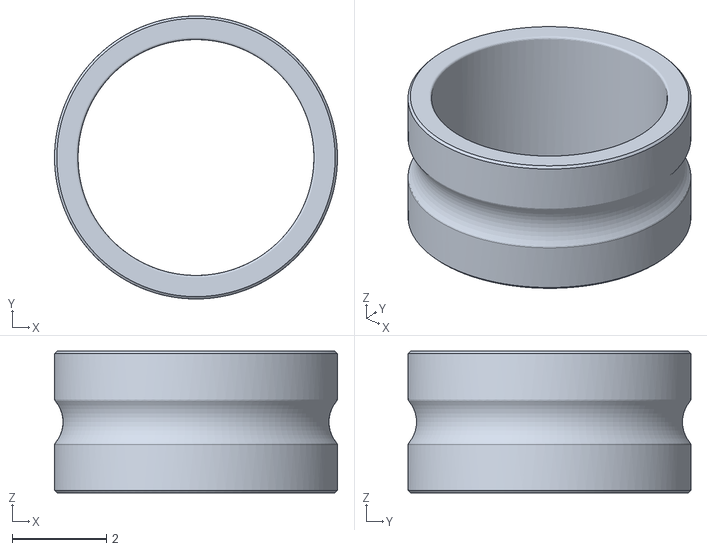
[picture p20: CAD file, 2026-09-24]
simulation/asset/ball_linear_complex/meshes/NoWeightBelt_1_BeltDrivenMotorHolder_27mmOffset_1_7804K135_Corrosion_Resistant_440C_Stainless_Steel_Ball_Bearing_1_Body10.stl
6.00 x 6.00 x 3.00

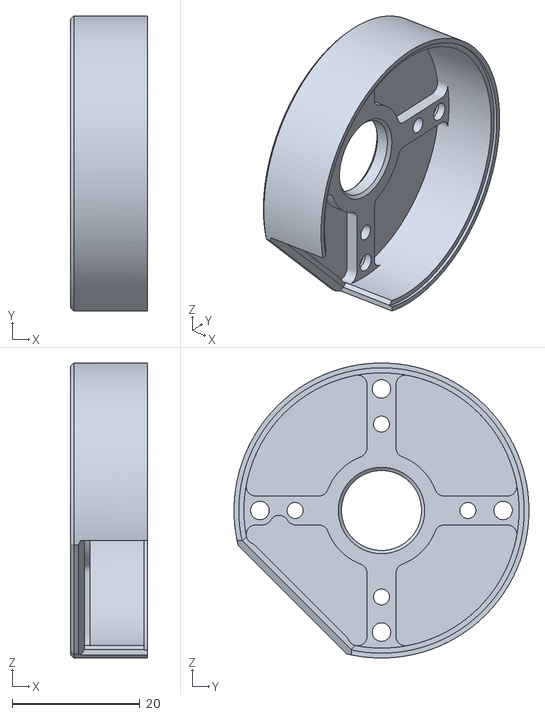
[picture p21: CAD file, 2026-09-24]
simulation/asset/ball_linear_complex/meshes/NoWeightBelt_1_BeltDrivenMotorHolder_27mmOffset_1_GL40II_3D_1_StatorBits_1_Body1.stl
12.0 x 46.1 x 46.1

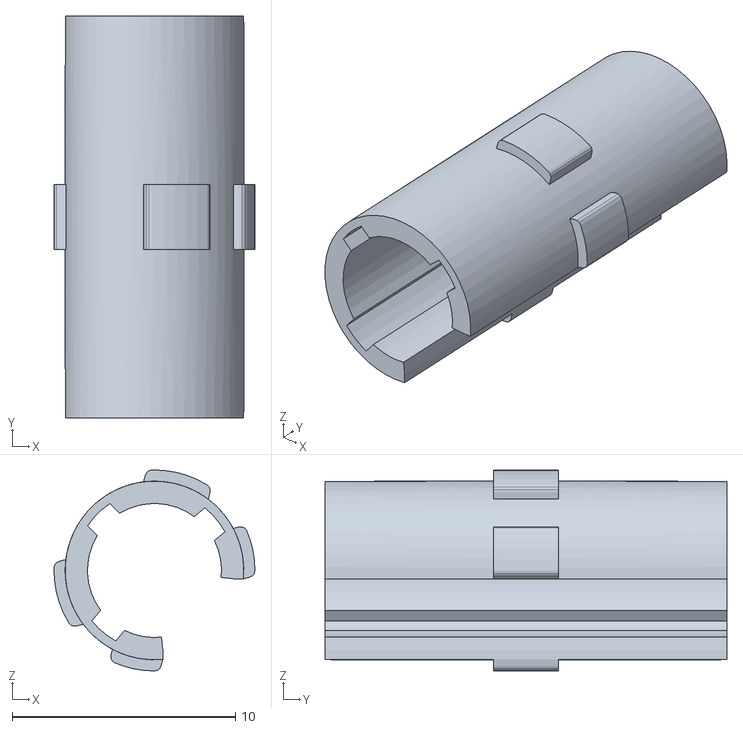
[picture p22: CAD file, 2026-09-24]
simulation/asset/ball_linear_complex/meshes/Bearing3.stl
9.00 x 18.0 x 9.00

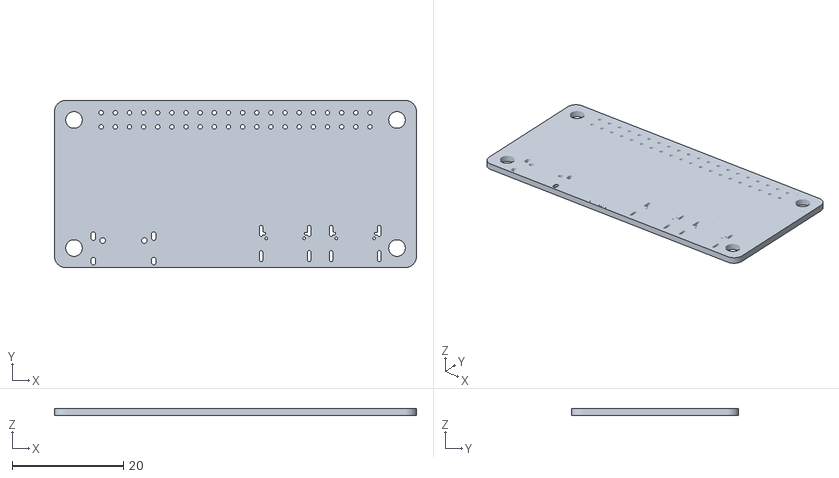
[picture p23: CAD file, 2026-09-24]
simulation/asset/ball_linear_complex/meshes/CapsuleHolder_1_Singular_Capsule_1_orange_pi_zero2w_details_26_04_2024_1_1_Body1.stl
65.0 x 30.0 x 1.29

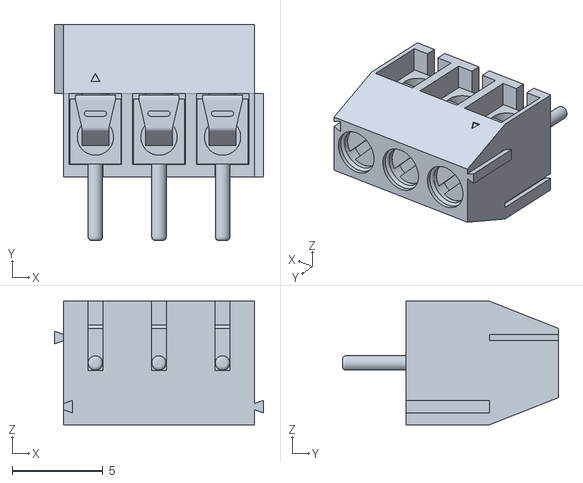
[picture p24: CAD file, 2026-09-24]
simulation/asset/ball_linear_complex/meshes/CapsuleHolder_1_Singular_Capsule_1_CAN_Bus_Breakout_Board_for_Seeed_Studio_XIAO_v1_1_Wire_Terminl_Block_3_5mm_v1_1_Body1.stl
11.5 x 11.9 x 6.80

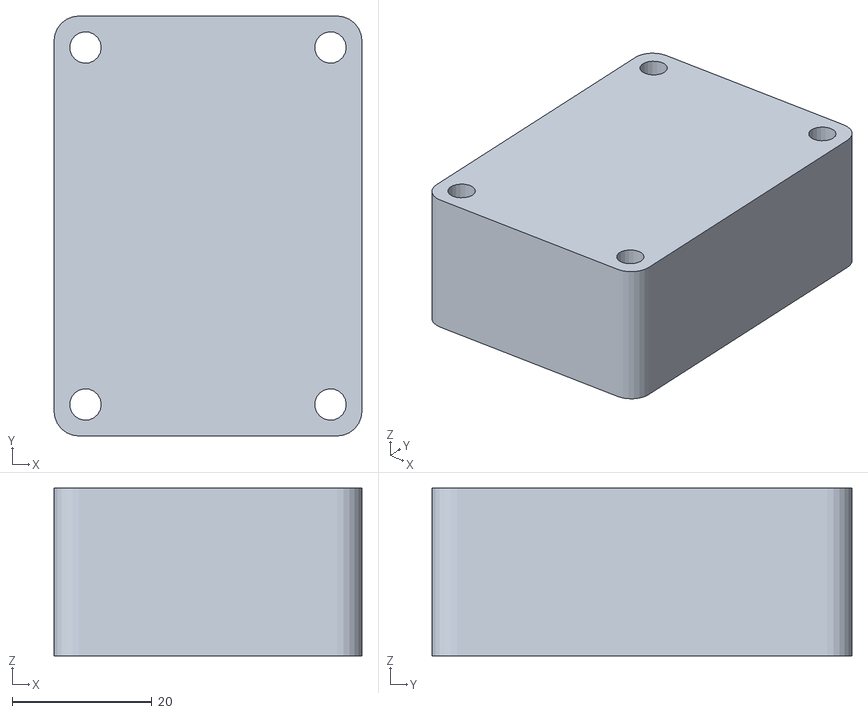
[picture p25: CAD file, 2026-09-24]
simulation/asset/ball_linear_complex/meshes/Weight.stl
44.0 x 60.0 x 24.0

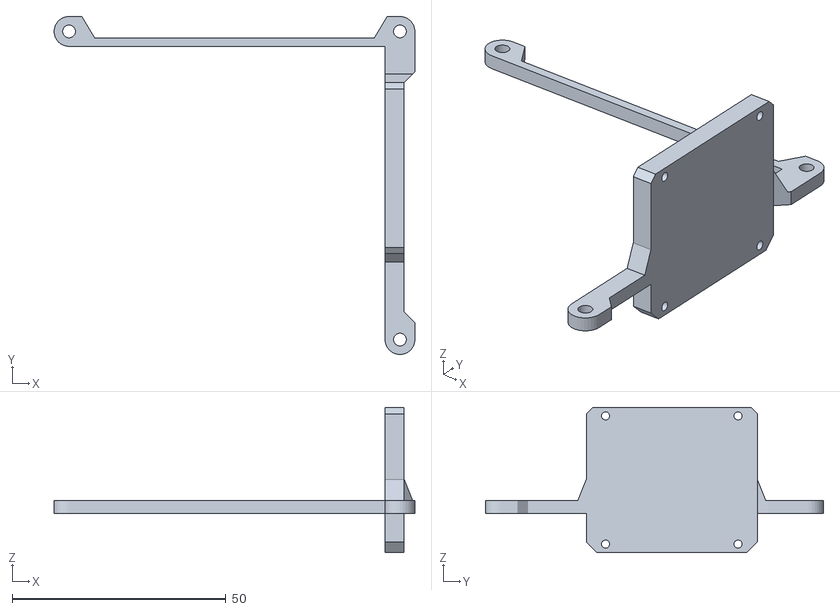
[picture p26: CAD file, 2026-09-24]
simulation/asset/ball_linear_complex/meshes/CapsuleHolder_1_Singular_Capsule_1_TM171_Mount_1_Body1.stl
84.4 x 79.1 x 34.0

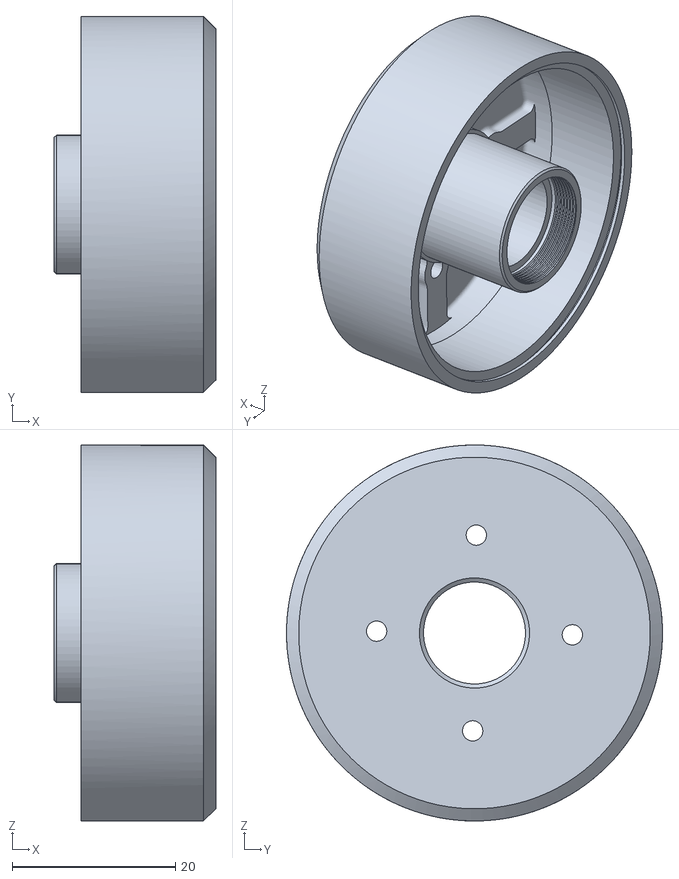
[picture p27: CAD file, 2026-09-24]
simulation/asset/ball_linear_complex/meshes/NoWeightBelt_1_BeltDrivenMotorHolder_27mmOffset_1_GL40II_3D_1_Rotor_1_Body1.stl
19.8 x 46.1 x 46.1

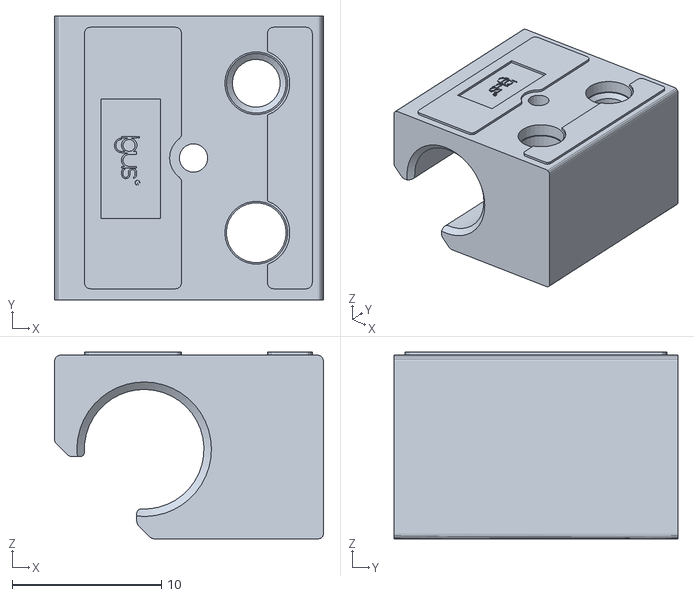
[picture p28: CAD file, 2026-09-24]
simulation/asset/ball_linear_complex/meshes/Pillow2.stl
18.0 x 19.0 x 12.5

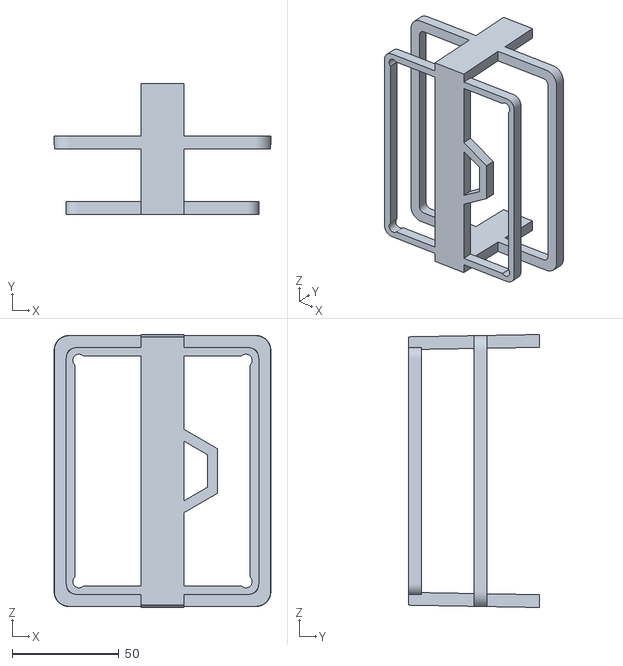
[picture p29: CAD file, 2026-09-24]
simulation/asset/ball_linear_complex/meshes/CapsuleHolder_1_Component6_1_Body1.stl
101.3 x 61.0 x 127.6

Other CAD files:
simulation/asset/ball_linear_complex/meshes/CapsuleHolder_1_Singular_Capsule_1_Battery_1_Body1.stl
simulation/asset/ball_linear_complex/meshes/NoWeightBelt_1_BeltDrivenMotorHolder_27mmOffset_1_Body59.stl
simulation/asset/ball_linear_complex/meshes/CapsuleHolder_1_Singular_Capsule_1_AN_04B_AN_04BP_01_1_Body1.stl
simulation/asset/ball_linear_complex/meshes/V2Frame_1_Tertiary_beam_2_Body1.stl
simulation/asset/ball_linear_complex/meshes/Bearing1.stl
simulation/asset/ball_linear_complex/meshes/Bearing2.stl
simulation/asset/ball_linear_complex/meshes/Bearing4.stl
simulation/asset/ball_linear_complex/meshes/Bolt1.stl
simulation/asset/ball_linear_complex/meshes/CapsuleHolder_1_Component6_1_Body2.stl
simulation/asset/ball_linear_complex/meshes/CapsuleHolder_1_Singular_Capsule_1_AN_04C_AN_04C_01_1_Body1.stl
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

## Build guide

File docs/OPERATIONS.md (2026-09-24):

# Operations

This assumes [`SETUP.md`](SETUP.md) is done and that a new or rebuilt robot
has passed [`validation.md`](validation.md). Run commands from the repository
root in the Python 3.12 environment.

## Safety

- Keep a physical power cutoff within reach. The latching E-stop (X), quitting
  and `scripts/disable_motors.py` all send the GL40 exit-control command. None
  of them cuts battery or bus power.
- Restrain or lift the robot for the first run of a new robot, checkpoint or
  flag. Secure the sphere before applying motor power for calibration.
- Keep the first water run of a checkpoint tethered, with manual override
  ready.

## Before each session

1. Power on the Orange Pi, the motors and the IMU.
2. Log in with `ssh -t`. The controller reads single key presses; without a
   TTY it exits before touching any hardware.

   ```bash
   ssh -t <user>@<robot-host> "cd <path-to-this-repository> && ./run.sh"
   ```

3. Check that `config/calibration.json` exists; to restore or create it, see
   [`SETUP.md`](SETUP.md#slider-calibration). The committed backup's motor IDs
   were remapped, not measured, so calibrate a new robot before its first run.

## Homing

Every slider target assumes the encoder zero is at the 0 mm hardstop; a wrong
zero shifts every target.

> [!WARNING]
> Without homing, the controller arms at the pose the drivers report,
> unverified, and immediately steps the sliders to the 114 mm centre. This is
> safe only after a trusted rehome.

Rehome after any mechanical disturbance, or whenever you do not trust where
the sliders are.

Use `rehome_auto.py`. The `--home` centring move did not always converge on
hardware.

```bash
python scripts/rehome_auto.py
```

It seeks the 0 mm hardstop at 8 rad/s for 4 s, disables the motors and waits
at `Press ENTER to zero encoders and hold at 0 mm...`. Check that every slider
is on its hardstop, then press Enter. It zeros the encoders, holds 0 mm at
1.5 rad/s until every motor is within 0.08 rad or 15 s pass, disables and
exits.

| Alternative | Behaviour |
|---|---|
| `python src/ballbot_terminal.py --home`, or `y` at the `run.sh` rehome prompt | Seeks at `--home-vel` (20 rad/s) for 5 s, zeros without confirmation, centres at 1.5 rad/s and starts control, armed. Fails after 15 s with `Sliders did not reach the 114 mm center after homing`. X is not read until control starts; only Ctrl+C stops homing. |
| `python src/ballbot_terminal.py --home-only` | Same homing, then disables and exits. Needs no TTY. |
| `python scripts/home_to_endstop.py` | Seeks at 20 rad/s for 5 s, zeros, and holds 0 mm enabled until Ctrl+C. |

- Every method takes the seek direction from `encoder_sign` in
  `calibration.json`, so home only after a measured calibration.
- `rehome_auto.py` and `home_to_endstop.py` use a fixed port
  ([`SETUP.md`](SETUP.md#serial-ports)).
- With `--no-telem`, homing proceeds with one live motor and the centring
  timeout becomes a warning.

## The run.sh menu

```bash
./run.sh
```

It runs the interpreter in `BALLBOT_PYTHON`
([`SETUP.md`](SETUP.md#python-environment)).

| Option | Runs | Hardware |
|---|---|---|
| 1 | `scripts/preflight_heuristic.py` (offline readiness check) | none |
| 2 | `scripts/calibrate_imu.py` ([`SETUP.md`](SETUP.md#imu-mounting)) | IMU |
| 3 | `scripts/calibrate_sliders.py` ([`SETUP.md`](SETUP.md#slider-calibration)) | motors, robot restrained |
| 4 | `ballbot_terminal.py --policy heuristic` | robot |
| 5 | checkpoint picker, then `--policy trained --policy-path <picked>` | robot |
| 6 | checkpoint picker, then `--preflight` | none |
| 7 | exit | |

Options 4 and 5 ask `Force a full rehome first ...? [y/N]`. Enter means no;
`y` adds `--home`.

The picker lists every `policies/*/policy_deployed.pt`; Enter picks
`BallbotVelComplexFlatDRLatency`. Folders with a `requires_smoothing` file are
tagged `legacy` and launched with [smoothing on](#trajectory-smoothing).

- `BALLBOT_POLICY` sets the checkpoint Enter picks. Give it as
  `policies/<dir>`, with or without `/policy_deployed.pt`; any other form
  falls back to entry 1.

  ```bash
  BALLBOT_POLICY=policies/BallbotVelRingCageComplexDR ./run.sh
  ```

- `BALLBOT_ARGS` is split on spaces and appended to option 4 and 5 launches,
  not option 6.

  ```bash
  BALLBOT_ARGS="--speed 0.15" ./run.sh
  ```

## Geometric controller

```bash
python src/ballbot_terminal.py --policy heuristic
```

Or `run.sh` option 4. `--heuristic-magnitude` sets how far the masses lean;
above about 0.07 the aligned slider already hits its travel limit. On a new
robot, start at 0.02:

```bash
python src/ballbot_terminal.py --policy heuristic --heuristic-magnitude 0.02
```

## Learned policy

```bash
# Land
python src/ballbot_terminal.py --policy trained \
    --policy-path policies/BallbotVelComplexFlatDRLatency/policy_deployed.pt

# Water
python src/ballbot_terminal.py --policy trained \
    --policy-path policies/BallbotVelRingCageComplexDR/policy_deployed.pt
```

`run.sh` option 5 preselects land; pick entry 3 for water. The other
checkpoints are in [`policies/README.md`](../policies/README.md).

Always pass `--policy-path`. The code default, `DEFAULT_POLICY_PATH`, still
names the retired `BallbotVelRingCageShellDR`, which then runs without the
smoother it needs.

At startup the checkpoint is shape-checked and its `env_config.yaml` is
compared with the runtime. On a mismatch the controller refuses to start
([`DEVELOPING.md`](DEVELOPING.md#env_configyaml-contract)). To run the same
checks without hardware, use `run.sh` option 6 or add `--preflight`; it prints
`PASS: ...` on success.

### Trajectory smoothing

Smoothing is off by default: the software PD smoother (`--kp 125`, `--kd 25`)
is a low-pass filter at about 1.78 Hz that the simulator does not model.
Checkpoints with a `requires_smoothing` file need it on. `run.sh` adds
`--no-no-trajectory-smoothing` for them; a hand-typed command must include
it.

With smoothing off, SPACE snaps the sliders to centre instead of ramping, and
`--kp`, `--kd` and their keys have no effect.

### Limits for the learned policy

- `--vel-limit` must be at least 10 rad/s (default 30); below that the sliders
  cannot build the lean. It is not a hard speed cap: logged motor speeds have
  exceeded it.
- `--action-scale` must be at least 0.8; leave it at 1.0. It is not a derate:
  below 0.8 the robot rolls but stops tracking the command.
- The floors apply at startup and to the keys. A P switch raises a lower
  velocity limit to 10 and resets a lower action scale to 1.0.
- To go slower, lower `--speed` or press N. For a first move on an unfamiliar
  robot, use `--speed 0.15`.
- Leave `--target-rate-limit` at 0; the simulator does not model it.

### Switching controllers (P)

P centres the sliders for 1 s, then swaps between the geometric controller
and the `--policy-path` checkpoint loaded at startup. Geometric launches load
it too, so `run.sh` option 4 switches to the retired default without its
smoother. To switch to the land checkpoint, launch with:

```bash
BALLBOT_ARGS="--policy-path policies/BallbotVelComplexFlatDRLatency/policy_deployed.pt" ./run.sh
```

`BALLBOT_ARGS` also applies to option 5, so set it for that launch only.

If the checkpoint failed to load, P is refused. To change checkpoints, quit
and relaunch.

## Flags

`python src/ballbot_terminal.py --help` prints the full list.

| Flag | Default | Note |
|---|---|---|
| `--policy` | `heuristic` | `heuristic` (geometric) or `trained` (learned) |
| `--policy-path` | retired checkpoint | Always pass it |
| `--speed` | 0.3 m/s | 0.05 to 0.7 |
| `--heuristic-magnitude` | 0.98 | 0 to 1 |
| `--action-scale` | 1.0 | 0 to 1; at least 0.8 for `trained` |
| `--vel-limit` | 30 rad/s | 0.2 to 100; at least 10 for `trained` |
| `--yaw-offset-deg` | 0 | [Aiming the drive axes](#aiming-the-drive-axes) |
| `--home`, `--home-only` | off | [Homing](#homing) |
| `--home-vel` | 20 rad/s | 0.2 to 100 |
| `--no-telem` | off | Allow silent motors; one must answer |
| `--no-no-trajectory-smoothing` | smoothing off | For `requires_smoothing` checkpoints |
| `--kp`, `--kd` | 125, 25 | Smoother gains |
| `--target-rate-limit` | 0 (off) | Leave at 0 |
| `--imu-port` | `$BALLBOT_IMU_PORT`, else autodetect | |
| `--motor-port` | `$BALLBOT_MOTOR_PORT`, else autodetect | Bridge port |
| `--motor-temp-limit`, `--drive-temp-limit` | 85 °C, 85 °C | Thermal stop |

## Keys

| Key | Action | Step, range |
|---|---|---|
| `W` / `S` | Move +X / −X | |
| `A` / `D` | Move +Y / −Y | |
| `SPACE` | Stop and centre | |
| `P` | Switch geometric / learned | |
| `N` / `M` | Speed (learned) or magnitude (geometric) down / up | speed 0.05 m/s, 0.05 to 0.7; magnitude 0.1, no effect above 1.0 |
| `[` / `]` | Action scale down / up | 0.1, 0.8 to 1.0 (learned) |
| `-` / `+` (or `_` / `=`, `C` / `V`) | Velocity limit down / up | 5 rad/s, 10 to 100 (learned), 0.2 to 100 (geometric) |
| `Q` / `E` | Rotate drive axes +15° / −15° | |
| `,` / `.` (or `<` / `>`) | kp down / up | 10, 5 to 1000 |
| `O` / `I` | kd down / up | 2, 1 to 200 |
| `X` | E-stop, latching | |
| `Ctrl+C` | Quit and disable the motors | |

W/A/S/D are fixed command-frame directions, not relative to the robot.
Diagonals are normalised; pressing a direction key cancels its opposite. Q does not quit.

### Aiming the drive axes

The command frame's yaw origin is the heading at which the IMU mounting was
captured, not the way the robot was set down. Tap W, then press Q or E (safe
while armed) until the robot drives the way you mean. The controller prints
the matching `--yaw-offset-deg` (again on exit) and shows it as `yawref`.

## Automatic stops

| Condition | Result |
|---|---|
| No movement key for 3 s | Target returns to 114 mm centre; stays armed |
| No movement key for 120 s | Motors disabled; next movement key re-arms |
| Motor feedback older than 5 s while armed | Disabled (`motor telemetry lost`); arming refused until feedback returns |
| IMU data older than 5 s | Disabled; program exits |
| Motor or drive at its limit (85 °C) | `THERMAL STOP`: disabled; clears 5 °C below the limits, then a new movement key re-arms |
| CAN send fails | Disabled |

Hold a movement key (terminal key repeat) to keep moving. With `--no-telem`,
one fresh motor is enough.

## Status line and logs

```text
policy=trained   speed=0.30m/s pos=[114, 114, 114]mm Tdrv=[31, 30, 31]C err=[1, 1, 1] dir=(+1.00,+0.00) yawref=+0 armed=True
```

- `pos`: mm from the encoder zero, motor order 0x08, 0x07, 0x06. 114 (or −114
  when that motor's `encoder_sign` is −1) is centre.
- `Tdrv`: drive temperature.
- `err`: GL40 status. 0 disabled, 1 enabled, 8+ a fault (names in
  `GL40_STATUS_NAMES`, `xiao_can/xiao_gl_motor.py`).

Each run logs to `logs/<policy>_policy_YYYYMMDD_HHMMSS.msgpack`, named after
the controller at launch: one record per policy step (at most 50 Hz) while a
movement command is active. `--no-log` turns it off; `--log-path` moves it.

Beside it, `<name>_can_errors.txt` gets a line whenever a motor's status code,
stale-feedback state or CAN send error changes, flagged `FAULT`,
`UNEXPECTED_DISABLE` or `STALE_RX`; the console prints it as `CAN ERR: ...`.
Look here first when a motor sticks. The record format is in
[`DEVELOPING.md`](DEVELOPING.md#run-logs).

## Disabling the motors

Stop any running session first, then:

```bash
python scripts/disable_motors.py
```

It sends exit-control to all three motors twice and prints
`Motors successfully disabled.` It autodetects the bridge only and exits at
once if none is found.

## Bench scripts

| Command | What it does | Motion |
|---|---|---|
| `python scripts/verify_xiao_firmware.py` | Reads the bridge firmware version; no CAN traffic | none |
| `python scripts/gl_bench.py read` | Prints position, velocity, torque, temperatures and status, drives disabled | none |
| `python scripts/gl_bench.py hold --confirm HOLD` | Enables and holds the current position for 1 s | holds |
| `python scripts/scan_can_motors.py` | Briefly enables each ID from 0x01 to 0x24 (1 rad/s limit) and lists which answer, and missing or extra IDs. IDs above 0x0F are not reported under their own ID. | brief |
| `python scripts/monitor_temps.py` | Prints temperatures every 2 s; warns at 50 °C, over limit at 60 °C | none |
| `python scripts/motor_test.py` | Drives `MOTOR_ID` (default 0x08) at 10 rad/s for 5 s toward 0 mm, if the script's `ENCODER_SIGN` (default +1) matches that motor's calibrated `encoder_sign` | yes |

Each opens the bridge port, so run them only with no control session running.
[`SETUP.md`](SETUP.md#serial-ports) lists the port each uses.

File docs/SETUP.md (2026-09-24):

# Setup

Run these steps on the robot computer, from the repository root. Then see
[`OPERATIONS.md`](OPERATIONS.md) to run the robot, and
[`validation.md`](validation.md) for a new or rebuilt robot.

## Python environment

The stack needs Python 3.12 with its headers and `libpython3.12`; the IMU
binding is built against it. With micromamba:

```bash
"${SHELL}" <(curl -L micro.mamba.pm/install.sh)   # no root; open a new shell afterwards
micromamba create -n py312 python=3.12 -y && micromamba activate py312
export BALLBOT_PYTHON="$(command -v python)"
```

Or a venv on a system Python 3.12
(`sudo apt install python3.12-dev python3.12-venv`):

```bash
python3.12 -m venv "$HOME/marble-py312"
export BALLBOT_PYTHON="$HOME/marble-py312/bin/python"
```

Install PyTorch separately; only `--policy trained`, `--preflight` and
`scripts/policy_sim_check.py` need it. `prepare_orangepi.sh` installs the rest.

```bash
"$BALLBOT_PYTHON" -m pip install torch --index-url https://download.pytorch.org/whl/cpu
```

The `torch.jit.load` `FutureWarning` is harmless.

## Build the IMU binding

Prerequisites:

- CMake 3.15 or later, Ninja, and `g++` with C++17.
- gcc-12. `CMakeLists.txt` pins the C compiler to
  `/usr/bin/aarch64-linux-gnu-gcc-12` (aarch64) or `/usr/bin/gcc-12` (x86_64)
  when present. Override with `CC` or `-DCMAKE_C_COMPILER=<path>`.
- vcpkg, which needs `git`, `curl`, `zip`, `unzip`, `tar` and `pkg-config`. It
  installs `eigen3`, `cserialport` and `fmt` from `vcpkg.json` at configure
  time.

  ```bash
  git clone https://github.com/microsoft/vcpkg "$HOME/vcpkg" && "$HOME/vcpkg/bootstrap-vcpkg.sh" -disableMetrics
  export VCPKG_ROOT="$HOME/vcpkg"
  ```

- `nanobind`, from the requirements file.

Then build and check:

```bash
./scripts/prepare_orangepi.sh
```

It installs the requirements, builds `imu_nanobind` with CMake and the vcpkg
toolchain, and runs the preflight. The preflight must end with
`PASS: heuristic policy files and safety bounds are ready`.
`WARN: calibration.json is absent` is expected until
[slider calibration](#slider-calibration). If a copy lost the file modes, run
`chmod +x run.sh scripts/prepare_orangepi.sh`.

`CMakePresets.json` is for editors (`$HOME/repo/` paths, Debug). The script
does not use it.

## Serial ports

The XIAO bridge and the IMU must be different devices; `ballbot_terminal.py`
refuses equal ports. Autodetection:

- XIAO bridge: the single port whose USB description, manufacturer, product or
  hardware ID contains `xiao`, `seeed`, `samd` or `arduino`. Failing that, the
  single non-STMicroelectronics `/dev/ttyACM*` or `/dev/ttyUSB*`. Zero or
  several candidates is an error that asks for `--motor-port`.
- IMU: the port described as `STMicroelectronics Virtual COM Port`.

If detection is ambiguous, set the ports:

```bash
export BALLBOT_IMU_PORT=/dev/ttyACM0
export BALLBOT_MOTOR_PORT=/dev/ttyACM1
```

| Script | Port source, in order |
|---|---|
| `src/ballbot_terminal.py` | `--motor-port` and `--imu-port`; `BALLBOT_MOTOR_PORT` and `BALLBOT_IMU_PORT`; autodetect |
| `scripts/calibrate_sliders.py`, `scripts/gl_bench.py` | `--motor-port`; `BALLBOT_MOTOR_PORT`; autodetect |
| `scripts/calibrate_imu.py` | `--imu-port`; `BALLBOT_IMU_PORT`; autodetect |
| `scripts/verify_xiao_firmware.py` | `--motor-port`; autodetect |
| `scripts/disable_motors.py`, `scripts/scan_can_motors.py` | autodetect only |
| `scripts/rehome_auto.py`, `scripts/home_to_endstop.py`, `scripts/monitor_temps.py`, `scripts/motor_test.py` | fixed `/dev/ttyACM1` (edit `port_name` in the script) |

### Environment variables

| Variable | Read by | Default |
|---|---|---|
| `BALLBOT_PYTHON` | `run.sh`, `scripts/prepare_orangepi.sh` | `/home/orangepi/repo/micromamba/envs/py312/bin/python` (the reference robot's) |
| `VCPKG_ROOT` | `scripts/prepare_orangepi.sh` | `/home/orangepi/repo/vcpkg` |

`BALLBOT_POLICY` and `BALLBOT_ARGS` configure `run.sh`
([`OPERATIONS.md`](OPERATIONS.md#the-runsh-menu)).

## Flash the bridge firmware

With motor power off, flash and verify the XIAO as in
[`FLASH_XIAO.md`](FLASH_XIAO.md).

## Calibration

- Slider mapping: `config/calibration.json` (gitignored), written by
  `scripts/calibrate_sliders.py`. Both controllers and homing need it.
- IMU mounting: the constant `IMU_QUAT_BASE_SENSOR_WXYZ` in
  `src/ballbot_runtime.py`. `scripts/calibrate_imu.py` checks it; no script
  writes it.

### Slider calibration

`config/calibration.robot-backup.json` is a reference only: its motor IDs were
remapped for this release, not measured
([`PROVENANCE.md`](../PROVENANCE.md#motor-ids)). Run this procedure once on the
restrained robot before its first control run. Recalibrate after replacing motors, sliders or other mechanical parts, or when
[section 3 of `validation.md`](validation.md#3-slider-zero-and-mapping) fails.

> [!CAUTION]
> Secure the sphere before you apply motor power. Keep an emergency power
> switch within reach.

1. Start `./run.sh` over `ssh -t`
   ([`OPERATIONS.md`](OPERATIONS.md#before-each-session)).
2. Option 1: offline readiness check.
3. Option 2: IMU mounting check ([below](#imu-mounting)).
4. Put the secured robot in the reference pose: +Y forward, +Z up.
5. Option 3, with motor power on:
   1. The drives are disabled. Push all three sliders by hand to the 0 mm
      fully extended hardstop, press Enter, and type `ZERO`. Anything else
      cancels without writing.
   2. For each motor (0x08, 0x07, 0x06), the script moves the slider 30 mm at
      5 rad/s to find the encoder sign, trying the other sign if it hits the
      hardstop. Answer which marked axis (X, Y or Z) the slider follows and
      whether the mass moved toward + or −. The slider returns to 0 mm.
   3. It writes `config/calibration.json` (`--output` to change).

   It aborts at 70 °C motor or 80 °C drive temperature, or on lost feedback.

   Do not use `scripts/rehome_auto.py` instead of pushing by hand on a new
   build, after a motor was replaced or remounted, or after a failed
   [slider check](validation.md#3-slider-zero-and-mapping). It takes the
   direction from the existing `config/calibration.json`; with a wrong sign it
   drives the slider away from the hardstop at 8 rad/s for 4 s.
6. Save the result as the backup:

   ```bash
   cp config/calibration.json config/calibration.robot-backup.json
   ```

To restore it later (for example on a reflashed Orange Pi):

```bash
cp -n config/calibration.robot-backup.json config/calibration.json
```

### IMU mounting

`IMU_QUAT_BASE_SENSOR_WXYZ` is the `imu_site` of the MuJoCo model `Sim_Model`
(in every `policies/*/robot.xml`), rotated +90° about the sensor Z axis.

| Command | What it does |
|---|---|
| `python scripts/calibrate_imu.py` | Prints the base axes and angular velocity in world coordinates, live |
| `python scripts/calibrate_imu.py --viz` | Live 3D view with tilt from vertical, on port 8080 (`--viz-port`) |
| `python scripts/calibrate_imu.py --capture-upright` | Solves the mounting rotation from a held reference pose |

Check it after any remount: at the reference pose the tilt reads about 0°. To
re-solve it:

1. Run `--capture-upright`. Hold the robot with the shell on the ground, the
   chassis vertical and +Y toward forward. Keep it still and press Enter.
2. The script averages 200 samples (`--samples`), warning on motion (median
   gyro above 0.05 rad/s, or more than 1° spread). It prints a quaternion for
   `IMU_QUAT_BASE_SENSOR_WXYZ` and compares it with the CAD mounting in 90°
   steps. The capture heading becomes the world yaw origin.
3. Nothing is written. Edit the constant, re-run `--viz`, and confirm the tilt
   reads about 0°.

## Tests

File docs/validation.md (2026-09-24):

# Bring-up checklist

For a new or rebuilt robot. Work in order; do not free-roll until every
earlier section passes. Run commands from the repository root.

## 1. Runtime and firmware

- `./scripts/prepare_orangepi.sh`, then `./run.sh` option 1: only the
  `calibration.json is absent` warning may remain.
- The bridge is flashed and verified ([`FLASH_XIAO.md`](FLASH_XIAO.md)).
- Startup sends `0xFB` (clear fault) then `0xFD` (disable) on `0x108`, `0x107`
  and `0x106`, never `0xFE` (encoder zero).
- Restrained, `python scripts/gl_bench.py read` shows fresh telemetry from
  `0x08`, `0x07` and `0x06` without motion. If one is missing,
  `python scripts/scan_can_motors.py` lists the IDs that answer.
- A launch without a TTY exits before opening hardware.

## 2. IMU transform

- Sphere secured, motor power off, reference pose (+Y forward, +Z up).
- `python scripts/calibrate_imu.py` (`./run.sh` option 2; `--viz` optional):
  base +Z points up and base +Y matches the marked forward direction.
- Rotate about each marked axis: no axis swaps or sign errors.
- On failure, check the TM171 quaternion convention first, then re-solve with
  `--capture-upright` ([`SETUP.md`](SETUP.md#imu-mounting)).

## 3. Slider zero and mapping

- Run `./run.sh` option 3 per [`SETUP.md`](SETUP.md#slider-calibration),
  sphere secured and moving masses visible.
- Each test motion moves the slider away from the 0 mm hardstop.
- `config/calibration.json` lists each motor and each of Slider-5/6/7 exactly
  once.

## 4. Homing and safety

- Restrained, `python src/ballbot_terminal.py --home-only` gets fresh
  telemetry before any motion, reaches the 0 mm hardstop without sustained
  impact, zeros, centres at 114 mm and disables.
- `python scripts/rehome_auto.py` pauses before zeroing and ends at 0 mm.
- With one motor's telemetry unplugged, arming is refused or the motors
  disable within 5 s.
- SPACE centres (a step, with smoothing off), Ctrl+C disables and quits, and
  X disables until restart.
- With no movement key, the sliders centre after 3 s and the motors disable
  after 120 s.
- With injected temperatures, the controller trips at 85 °C motor or drive and
  re-arms only below 80 °C, on a new movement command.

## 5. Geometric controller

- Lift or fixture the sphere so it cannot roll.
- Start `python src/ballbot_terminal.py --policy heuristic --heuristic-magnitude 0.02`.
  Raise the magnitude only after each direction is confirmed.
- W keeps the mass toward command-frame +X as the shell is rotated slowly; A
  targets +Y. WA, WD, SA and SD are normalised diagonals.
- Targets stay within travel and return to centre.

## 6. Learned policy

- Off-robot first: `./run.sh` option 6 and `scripts/policy_sim_check.py`
  ([`DEVELOPING.md`](DEVELOPING.md#offline-checks)).
- Launch the land default as in
  [`OPERATIONS.md`](OPERATIONS.md#learned-policy): explicit `--policy-path`,
  default limits.
- Under sustained slew at 30 rad/s, watch `Tdrv` and confirm the 85 °C trip.
- Joint order is Slider-5, Slider-6, Slider-7; output signs match simulation.
- Logged observations replayed off-robot through the same TorchScript give the
  same actions.
- Measure IMU-to-CAN latency and the achieved rate (`t_s` in the log).
  Training modelled 0 to 40 ms of sensor delay (`delay_max_lag: 2`) and no
  action delay.
- P centres for 1 s, switches controller, and resumes only while the movement
  command is still active.
- Short W, D, S and A runs in a clear area, with X and the power cutoff at
  hand.
- First water session tethered, with manual override ready.

## 7. Record results

Add to this file: date, hardware revision, calibration backup name, policy
md5, PyTorch version, inference P50/P95, serial ports, homing peak torque,
temperature behaviour, pass/fail notes.

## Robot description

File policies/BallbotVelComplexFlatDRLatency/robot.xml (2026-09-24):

<mujoco model="Sim_Model">
  <compiler angle="radian" meshdir="./" texturedir="./"/>

  <default>
    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
  </default>

  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

  <worldbody>
    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
    <light pos="-0.5 0.5 3" dir="0 0 -1" type="directional"/>
    <body name="base_link">
      <inertial pos="0.0103932 0.0101 -0.0104149" quat="-0.34258 0.316693 0.0103017 0.884442" mass="3.13212" diaginertia="0.0487114 0.0621341 0.0628177"/>
      <joint name="base_link_free" type="free"/>
      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
      <body name="base-2" pos="0 -0.0245 0.03" quat="0 0 -0.707107 0.707107">
        <inertial pos="-1.07005e-05 0.0300003 0.0129248" quat="-0.000187147 0.707052 0.000193375 0.707162" mass="0.128212" diaginertia="4.72564e-05 2.65279e-05 2.5293e-05"/>
        <joint name="base_link_Slider-5" pos="0 0.0300001 0.0037" axis="0 1 0" type="slide" limited="true" range="-0.114 0.106" armature="0.03134" frictionloss="0.2"/>
        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
        <body name="Bolt2-2" pos="0 -0.04 0">
          <inertial pos="0.0175 0.0855 0.0120317" mass="0.000646985" diaginertia="1.37396e-08 1.37396e-08 2.53547e-09"/>
          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
        </body>
        <body name="Bolt-4-2" pos="0 -0.04 0">
          <inertial pos="0.0175 0.0545 0.0120317" mass="0.000646985" diaginertia="1.37396e-08 1.37396e-08 2.53547e-09"/>
          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
        </body>
        <body name="Bolt3-2" pos="0 -0.04 0">
          <inertial pos="-0.0175 0.0545 0.0120317" mass="0.000646985" diaginertia="1.37396e-08 1.37396e-08 2.53547e-09"/>
          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
        </body>
        <body name="Pillow1-2" pos="0 -0.04 0">
          <inertial pos="-0.0147422 0.0905834 0.00873522" quat="0.387781 0.429954 -0.546876 0.604724" mass="0.0166997" diaginertia="1.01281e-06 7.16626e-07 6.77395e-07"/>
          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
          <body name="Bearing1-2" pos="0 0 -1.62936e-12">
            <inertial pos="-0.0106124 0.0905 0.00811238" quat="0.653282 0.653282 0.270598 -0.270598" mass="0.000480715" diaginertia="1.60509e-08 1.4431e-08 5.91877e-09"/>
            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
          </body>
        </body>
        <body name="Bolt1-2" pos="0 -0.04 0">
          <inertial pos="-0.0175 0.0855 0.0120317" mass="0.000646985" diaginertia="1.37396e-08 1.37396e-08 2.53547e-09"/>
          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
        </body>
        <body name="Pillow3-2" pos="0 -0.04 0">
          <inertial pos="-0.0147422 0.0494163 0.00873522" quat="0.429776 0.387979 -0.604444 0.547186" mass="0.0166997" diaginertia="1.01281e-06 7.16617e-07 6.77402e-07"/>
          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
          <body name="Bearing3-2" pos="0 0 0">
            <inertial pos="-0.0106124 0.0495 0.00811238" quat="0.653282 0.653282 0.270598 -0.270598" mass="0.000480715" diaginertia="1.6051e-08 1.4431e-08 5.91877e-09"/>
            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
          </body>
        </body>
        <body name="Pillow2-2" pos="0 -0.04 0">
          <inertial pos="0.0147422 0.0905837 0.00873522" quat="0.604444 0.547187 -0.429776 0.387979" mass="0.0166997" diaginertia="1.01281e-06 7.16617e-07 6.77402e-07"/>
          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
          <body name="Bearing2-2" pos="0 0 0">
            <inertial pos="0.0106124 0.0905 0.00811238" quat="0.653281 0.653281 -0.270598 0.270598" mass="0.000480715" diaginertia="1.6051e-08 1.44311e-08 5.91877e-09"/>
            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
          </body>
        </body>
        <body name="Pillow4-2" pos="0 -0.04 0">
          <inertial pos="0.0147422 0.0494166 0.00873522" quat="0.546876 0.604724 -0.387781 0.429954" mass="0.0166997" diaginertia="1.01281e-06 7.16626e-07 6.77395e-07"/>
          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
          <body name="Bearing4-2" pos="0 0 0">
            <inertial pos="0.0106124 0.0495 0.00811238" quat="0.653281 0.653281 -0.270598 0.270598" mass="0.000480715" diaginertia="1.6051e-08 1.44311e-08 5.91877e-09"/>
            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
          </body>
        </body>
        <body name="Weight-2" pos="0 0 0">
          <inertial pos="0 0.03 0.03" quat="0.5 0.5 -0.5 0.5" mass="0.491952" diaginertia="0.000219118 0.000165752 0.000100594"/>
          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
          <body name="LBolt4-2" pos="0.0175 0.0045 0.0259">
            <inertial pos="0 0 0.00206729" mass="0.00428397" diaginertia="5.87674e-07 5.87674e-07 1.20766e-08"/>
            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
          </body>
          <body name="LBolt1-2" pos="-0.0175 0.0555 0.0259" quat="1 0 0 0">
            <inertial pos="0 0 0.00206729" mass="0.00428397" diaginertia="5.87674e-07 5.87674e-07 1.20766e-08"/>
            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
          </body>
          <body name="LBolt2-2" pos="0.0175 0.0555 0.0259">
            <inertial pos="0 0 0.00206729" mass="0.00428397" diaginertia="5.87674e-07 5.87674e-07 1.20766e-08"/>
            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
          </body>
          <body name="LBolt3-2" pos="-0.0175 0.0045 0.0259">
            <inertial pos="0 0 0.00206729" mass="0.00428397" diaginertia="5.87674e-07 5.87674e-07 1.20766e-08"/>
            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
          </body>
        </body>
      </body>
      <body name="base-1" pos="-0.0245 0.03 0" quat="0 -0.707107 0 0.707107">
        <inertial pos="-1.07005e-05 0.0300003 0.0129248" quat="-0.000187147 0.707052 0.000193375 0.707162" mass="0.128212" diaginertia="4.72564e-05 2.65279e-05 2.5293e-05"/>
        <joint name="base_link_Slider-6" pos="0 0.0300001 0.0037" axis="0 -1 0" type="slide" limited="true" range="-0.114 0.106" armature="0.03134" frictionloss="0.2"/>
        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
        <body name="Weight-1" pos="0 0 0">
          <inertial pos="0 0.03 0.03" quat="0.5 0.5 -0.5 0.5" mass="0.491952" diaginertia="0.000219118 0.000165752 0.000100594"/>
          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
          <body name="LBolt1-1" pos="-0.0175 0.0555 0.0259" quat="1 0 0 0">
            <inertial pos="0 0 0.00206729" mass="0.00428397" diaginertia="5.87674e-07 5.87674e-07 1.20766e-08"/>
            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
          </body>
          <body name="LBolt2-1" pos="0.0175 0.0555 0.0259">
            <inertial pos="0 0 0.00206729" mass="0.00428397" diaginertia="5.87674e-07 5.87674e-07 1.20766e-08"/>
            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
          </body>
          <body name="LBolt3-1" pos="-0.0175 0.0045 0.0259">
            <inertial pos="0 0 0.00206729" mass="0.00428397" diaginertia="5.87674e-07 5.87674e-07 1.20766e-08"/>
            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
          </body>
          <body name="LBolt4-1" pos="0.0175 0.0045 0.0259">
            <inertial pos="0 0 0.00206729" mass="0.00428397" diaginertia="5.87674e-07 5.87674e-07 1.20766e-08"/>
            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
          </body>
        </body>
        <body name="Pillow3-1" pos="0 -0.04 0">
          <inertial pos="-0.0147422 0.0494163 0.00873522" quat="0.429776 0.387979 -0.604444 0.547186" mass="0.0166997" diaginertia="1.01281e-06 7.16617e-07 6.77402e-07"/>
          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
          <body name="Bearing3-1" pos="0 0 0">
            <inertial pos="-0.0106124 0.0495 0.00811238" quat="0.653282 0.653282 0.270598 -0.270598" mass="0.000480715" diaginertia="1.6051e-08 1.4431e-08 5.91877e-09"/>
            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
          </body>
        </body>
        <body name="Pillow2-1" pos="0 -0.04 0">
          <inertial pos="0.0147422 0.0905837 0.00873522" quat="0.604444 0.547187 -0.429776 0.387979" mass="0.0166997" diaginertia="1.01281e-06 7.16617e-07 6.77402e-07"/>
          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
          <body name="Bearing2-1" pos="0 0 0">
            <inertial pos="0.0106124 0.0905 0.00811238" quat="0.653281 0.653281 -0.270598 0.270598" mass="0.000480715" diaginertia="1.6051e-08 1.44311e-08 5.91877e-09"/>
            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
          </body>
        </body>
        <body name="Pillow4-1" pos="0 -0.04 0">
          <inertial pos="0.0147422 0.0494166 0.00873522" quat="0.546876 0.604724 -0.387781 0.429954" mass="0.0166997" diaginertia="1.01281e-06 7.16626e-07 6.77395e-07"/>
          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
          <body name="Bearing4-1" pos="0 0 0">
            <inertial pos="0.0106124 0.0495 0.00811238" quat="0.653281 0.653281 -0.270598 0.270598" mass="0.000480715" diaginertia="1.6051e-08 1.44311e-08 5.91877e-09"/>
            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
          </body>
        </body>
        <body name="Pillow1-1" pos="0 -0.04 0">
          <inertial pos="-0.0147422 0.0905834 0.00873522" quat="0.387781 0.429954 -0.546876 0.604724" mass="0.0166997" diaginertia="1.01281e-06 7.16626e-07 6.77395e-07"/>
          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
          <body name="Bearing1-1" pos="0 0 -1.62936e-12">
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

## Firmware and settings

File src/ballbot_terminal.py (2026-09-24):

#!/usr/bin/env python3
"""SSH-friendly terminal controller with heuristic and trained TorchScript policies."""

from __future__ import annotations

import dataclasses
import math
import os
from datetime import datetime
from pathlib import Path
import select
import sys
import termios
import threading
import time
import tty
from typing import Annotated, Literal

import msgpack
import numpy as np
import tyro

ROOT = Path(__file__).resolve().parent
PROJECT_ROOT = ROOT.parent
for d in (
    ROOT,
    ROOT / "src",
    ROOT / "xiao_can",
    ROOT / "hardware_bindings",
    PROJECT_ROOT,
    PROJECT_ROOT / "src",
    PROJECT_ROOT / "xiao_can",
    PROJECT_ROOT / "hardware_bindings",
):
    if d.exists() and str(d) not in sys.path:
        sys.path.insert(0, str(d))

from ballbot_runtime import (
    CALIBRATION_FILE,
    DEFAULT_POLICY_PATH,
    IDLE_POSITION_MM,
    ImuState,
    HeuristicPolicy,
    wrap_to_pi,
    JOINT_NAMES,
    MAX_TRAVEL_MM,
    MotorJointMapper,
    MOTOR_IDS,
    POLICY_FRAME_DIM,
    POLICY_HZ,
    SliderCalibration,
    TrainedPolicy,
    mm_to_rad,
)
from xiao_gl_motor import GL40_FAULT_CODES, gl40_status_name

LOG_DIR = PROJECT_ROOT / "logs"

CONTROL_HZ = 100.0
COMMAND_TTL_S = 3.0
IDLE_DISARM_S = 120.0
SWITCH_CENTER_S = 1.0
TELEMETRY_TIMEOUT_S = 5.0
HOME_VELOCITY_RAD_S = 20.0
HOME_SEEK_S = 5.0
# Gentle approach to the 114 mm centre; at seek speed it overshoots the tolerance.
CENTER_VELOCITY_RAD_S = 1.5
MOTOR_TEMP_LIMIT_C = 85.0
DRIVE_TEMP_LIMIT_C = 85.0
TEMP_HYSTERESIS_C = 5.0
MAX_COMMAND_SPEED_MPS = 0.7
# Degrees per Q/E press when re-aiming the command frame.
YAW_STEP_DEG = 15.0
DEFAULT_COMMAND_SPEED_MPS = 0.3
DEFAULT_HEURISTIC_MAGNITUDE = 0.98
DEFAULT_CONTROL_VEL_LIMIT_RAD_S = 30.0
MAX_VEL_LIMIT_RAD_S = 100.0
MIN_VEL_LIMIT_RAD_S = 0.2
VEL_LIMIT_STEP_RAD_S = 5.0
# Below this the trained policy's targets clip every step and the robot barely moves
# (docs/OPERATIONS.md).
TRAINED_MIN_VEL_LIMIT_RAD_S = 10.0
# Not a derate (use --speed/--vel-limit): below this the policy stops tracking the command.
TRAINED_MIN_ACTION_SCALE = 0.8

def _as_f64_list(values: np.ndarray | list[float]) -> list[float]:
    return [float(v) for v in np.asarray(values, dtype=np.float64).reshape(-1)]


class PolicyRunLogger:
    """Append-only msgpack stream of heuristic/trained policy observation/action traces.

    File layout: concatenated msgpack objects. First object is a header dict
    (`type="header"`); each subsequent object is a step (`type="step"`).
    Read with `msgpack.Unpacker(f, raw=False)` or
    `hardware_bindings.common.publisher.unpack_data_from_file`.
    """

    def __init__(self, path: Path, *, policy: str, yaw_ref_deg: float = 0.0) -> None:
        path.parent.mkdir(parents=True, exist_ok=True)
        self.path = path
        self._file = path.open("wb")
        self.step = 0
        header = {
            "type": "header",
            "schema_version": 2,
            "policy": str(policy),
            "policy_hz": float(POLICY_HZ),
            "frame_dim": int(POLICY_FRAME_DIM),
            "joint_names": list(JOINT_NAMES),
            "motor_ids": [int(mid) for mid in MOTOR_IDS],
            "obs_terms": [
                "ang_vel_world[3]",
                "cmd_world_xy[2]",
                "joint_pos[3]",
                "joint_vel[3]",
                "last_action[3]",
                "rotation_world_base[9]",
            ],
            "created_at": datetime.now().isoformat(timespec="seconds"),
            # World yaw the command frame's +X pointed at when the log opened. Per-step
            # `yaw_ref_deg` is authoritative: the operator can re-aim it mid-run.
            "yaw_ref_deg": float(yaw_ref_deg),
        }
        self._pack(header)
        self._can_error_path = path.with_name(path.stem + "_can_errors.txt")
        self._can_error_file = self._can_error_path.open("a", encoding="utf-8")
        self._can_error_file.write(
            f"# CAN/GL40 status log for {path.name}\n"
            f"# created_at={header['created_at']} policy={policy}\n"
        )
        self._can_error_file.flush()

    def log_can_event(self, t_s: float, message: str) -> None:
        line = f"{t_s:9.3f}  {message}\n"
        if self._can_error_file is not None:
            self._can_error_file.write(line)
            self._can_error_file.flush()
        print(f"\nCAN ERR: {message}", flush=True)

    def _pack(self, obj: dict) -> None:
        self._file.write(msgpack.packb(obj, use_bin_type=True))

    def log(
        self,
        *,
        t_s: float,
        policy: str,
        frame: np.ndarray,
        action: np.ndarray,
        target: np.ndarray,
        virtual_pos: np.ndarray,
        virtual_vel: np.ndarray,
        motor_pos: np.ndarray,
        motor_vel: np.ndarray,
        motor_torque: np.ndarray,
        motor_temp: np.ndarray,
        drive_temp: np.ndarray,
        error_code: np.ndarray,
        mode_status: np.ndarray,
        feedback_age_s: np.ndarray,
        direction: np.ndarray,
        command_speed: float,
        action_scale: float,
        vel_limit: float,
        target_rate_limit: float = 0.0,
        kp: float,
        kd: float,
        armed: bool,
        send_error: str | None,
        yaw_ref_deg: float = 0.0,
    ) -> None:
        frame = np.asarray(frame, dtype=np.float64).reshape(-1)
        if frame.shape[0] != POLICY_FRAME_DIM:
            raise ValueError(f"expected {POLICY_FRAME_DIM}D frame, got {frame.shape}")
        err = [int(x) for x in np.asarray(error_code).reshape(-1)]
        record = {
            "type": "step",
            "t_s": float(t_s),
            "step": int(self.step),
            "policy": str(policy),
            "obs": _as_f64_list(frame),
            "action": _as_f64_list(action),
            "target_m": _as_f64_list(target),
            "virtual_pos": _as_f64_list(virtual_pos),
            "virtual_vel": _as_f64_list(virtual_vel),
            "motor_pos_rad": _as_f64_list(motor_pos),
            "motor_vel_rad_s": _as_f64_list(motor_vel),
            "motor_torque_nm": _as_f64_list(motor_torque),
            "motor_temp_c": _as_f64_list(motor_temp),
            "drive_temp_c": _as_f64_list(drive_temp),
            "error_code": err,
            "error_name": [gl40_status_name(c) for c in err],
            "mode_status": [int(x) for x in np.asarray(mode_status).reshape(-1)],
            "feedback_age_s": _as_f64_list(feedback_age_s),
            "direction": _as_f64_list(direction[:2]),
            "command_speed_mps": float(command_speed),
            "action_scale": float(action_scale),
            "vel_limit_rad_s": float(vel_limit),
            "target_rate_limit_mps": float(target_rate_limit),
            "kp": float(kp),
            "kd": float(kd),
            "armed": bool(armed),
            "send_error": None if send_error is None else str(send_error),
            # `obs` (cmd_world_xy, ang_vel_world, rotation_world_base) is expressed in the
            # command frame, so it is only comparable across steps at equal yaw_ref_deg.
            "yaw_ref_deg": float(yaw_ref_deg),
        }
        self._pack(record)
        self.step += 1
        if self.step % 10 == 0:
            self._file.flush()

    def close(self) -> None:
        if self._file is not None:
            self._file.flush()
            self._file.close()
            self._file = None
        if getattr(self, "_can_error_file", None) is not None:
            self._can_error_file.flush()
            self._can_error_file.close()
            self._can_error_file = None


class TerminalInput:
    def __init__(self, command_ttl_s: float = COMMAND_TTL_S):
        self.command_ttl_s = command_ttl_s
        self.key_expiry = {"w": 0.0, "a": 0.0, "s": 0.0, "d": 0.0}
        self.stop_requested = False
        self.quit_requested = False
        self.estop_requested = False
        self.switch_requested = False
        self.speed_delta = 0
        self.scale_delta = 0
        self.vel_limit_delta = 0
        self.stiffness_delta = 0
        self.damping_delta = 0
        self.yaw_delta = 0
        self.last_movement_at = 0.0
        self._lock = threading.Lock()
        self._running = True
        self._thread = threading.Thread(target=self._read_loop, daemon=True)
        self._thread.start()

    def _read_loop(self) -> None:
        if not sys.stdin.isatty():
            # Without `ssh -t` stdin is a pipe and `tty.setcbreak` throws. Flush so the
            # message shows before the run loop sees `quit_requested`.
            print(
                "\nInteractive TTY required for keyboard control; "
                "use `ssh -t` when launching remotely.",
                flush=True,
            )
            with self._lock:
                self.quit_requested = True
            return
        fd = sys.stdin.fileno()
        old_settings = termios.tcgetattr(fd)
        try:
            tty.setcbreak(fd)
            while self._running:
                if not select.select([sys.stdin], [], [], 0.05)[0]:
                    continue
                key = sys.stdin.read(1)
                now = time.monotonic()
                with self._lock:
                    lower = key.lower()
                    if lower in self.key_expiry:
                        opposite = {"w": "s", "s": "w", "a": "d", "d": "a"}[lower]
                        self.key_expiry[opposite] = 0.0
                        self.key_expiry[lower] = now + self.command_ttl_s
                        self.last_movement_at = now
                        self.stop_requested = False
                    elif key == " ":
                        self._clear_directions()
                        self.stop_requested = True
                    elif lower == "x":
                        self._clear_directions()
                        self.estop_requested = True
                    elif lower == "p":
                        self.switch_requested = True
                    elif lower == "m":
                        self.speed_delta += 1
                    elif lower == "n":
                        self.speed_delta -= 1
                    elif key == "]":
                        self.scale_delta += 1
                    elif key == "[":
                        self.scale_delta -= 1
                    elif key in ("=", "+") or lower == "v":
                        self.vel_limit_delta += 1
                    elif key in ("-", "_") or lower == "c":
                        self.vel_limit_delta -= 1
                    elif key in (",", "<"):
                        self.stiffness_delta -= 1
                    elif key in (".", ">"):
                        self.stiffness_delta += 1
                    elif lower == "o":
                        self.damping_delta -= 1
                    elif lower == "i":
                        self.damping_delta += 1
                    elif lower == "q":
                        self.yaw_delta += 1
                    elif lower == "e":
                        self.yaw_delta -= 1
        finally:
            termios.tcsetattr(fd, termios.TCSADRAIN, old_settings)

    def _clear_directions(self) -> None:
        for key in self.key_expiry:
            self.key_expiry[key] = 0.0

    def snapshot(self) -> dict:
        now = time.monotonic()
        with self._lock:
            x = float(self.key_expiry["w"] > now) - float(self.key_expiry["s"] > now)
            y = float(self.key_expiry["a"] > now) - float(self.key_expiry["d"] > now)
            direction = np.array([x, y], dtype=np.float32)
            norm = float(np.linalg.norm(direction))
            if norm > 0.0:
                direction /= norm
            result = {
                "direction": direction,
                "last_movement_at": self.last_movement_at,
                "stop": self.stop_requested,
                "quit": self.quit_requested,
                "estop": self.estop_requested,
                "switch": self.switch_requested,
                "speed_delta": self.speed_delta,
                "scale_delta": self.scale_delta,
                "vel_limit_delta": self.vel_limit_delta,
                "stiffness_delta": self.stiffness_delta,
                "damping_delta": self.damping_delta,
                "yaw_delta": self.yaw_delta,
            }
            self.stop_requested = False
            self.estop_requested = False
            self.switch_requested = False
            self.speed_delta = 0
            self.scale_delta = 0
            self.vel_limit_delta = 0
            self.stiffness_delta = 0
            self.damping_delta = 0
            self.yaw_delta = 0
            return result

    def stop(self) -> None:
        self._running = False
        self._thread.join(timeout=0.2)


class BallbotController:
    def __init__(self, args: "Args"):
        self.args = args
        if args.imu_port and args.motor_port and args.imu_port == args.motor_port:
            raise ValueError("IMU and XIAO motor bridge must use different serial ports")
        self.calibration = SliderCalibration.load(Path(args.calibration))
        self.mapper = MotorJointMapper(self.calibration)
        self.heuristic = HeuristicPolicy()
        self.trained: TrainedPolicy | None = None
        self.active_policy_name = args.policy
        self.command_speed = args.speed
        self.heuristic_magnitude = args.heuristic_magnitude
        # World yaw that the command frame calls +X (the W key). 0 = the frame the IMU
        # mount calibration left behind, whose yaw origin is unrelated to which way the
        # robot is set down or driven from. Q/E turn it; see rotate_yaw_reference.
        self.yaw_reference_rad = wrap_to_pi(math.radians(args.yaw_offset_deg))
        self.action_scale = args.action_scale
        self.last_action = np.zeros(3, dtype=np.float32)
        self.current_joint_target = np.zeros(3, dtype=np.float64)
        self.virtual_joint_pos = np.zeros(3, dtype=np.float64)
        self.virtual_joint_vel = np.zeros(3, dtype=np.float64)
        self.last_policy_step = 0.0
        self.switch_until = 0.0
        self.pending_policy_name: str | None = None
        self.armed = False
        self.estopped = False
        self.thermal_lock = False
        self.last_thermal_poll = 0.0
        self.last_imu_counter = -1
        self.last_imu_update = time.monotonic()
        self._shutdown = False
        self.policy_logger: PolicyRunLogger | None = None
        self._run_started_at = 0.0
        self._last_can_error_codes: tuple[int, ...] | None = None
        self._last_can_send_error: str | None = None
        self._last_can_stale_mask: tuple[bool, ...] | None = None

        policy_exists = Path(args.policy_path).exists()
        if self.active_policy_name == "trained" or policy_exists:
            try:
                self._ensure_trained_policy()
            except Exception as exc:
                if self.active_policy_name == "trained":
                    raise
                print(
                    f"\nTrained policy unavailable ({exc}); "
                    "heuristic control remains usable."
                )

        from hardware_bindings.imu.py_imu import IMU
        from xiao_gl_motor import GL40, GL_MODE_POS_VEL, GLMotorController

        print("Initializing fixed-pose TM171 IMU...")
        self.imu = IMU(port_name=args.imu_port)
        time.sleep(1.0)

        self.vel_limit = float(args.vel_limit)
        self.home_vel = float(args.home_vel)
        self.kp = float(args.kp)
        self.kd = float(args.kd)
        self.no_trajectory_smoothing = bool(args.no_trajectory_smoothing)
        self.target_rate_limit = float(getattr(args, "target_rate_limit", 0.0))
        motor_setup = [[motor_id, "xiao", GL40] for motor_id in MOTOR_IDS]
        print("Initializing XIAO serial-to-CAN motor bridge...")
        try:
            self.motor = GLMotorController(
                motor_setup,
                control_mode=GL_MODE_POS_VEL,
                default_vel_limit=self.vel_limit,
                port_name=args.motor_port,
            )
        except Exception:
            self.imu.shutdown()
            raise
        self.motor.should_print_send = False
        self.motor.should_print_recv = False

    def _ensure_trained_policy(self) -> TrainedPolicy:
        if self.trained is None:
            print(f"\nLoading trained TorchScript policy: {self.args.policy_path}")
            self.trained = TrainedPolicy(Path(self.args.policy_path), self.action_scale)
            print("Policy preflight passed.")
        return self.trained

    def _motor_feedback_fresh(self) -> bool:
        """True when motor RX is acceptable for the current --no-telem setting.

        Default: every motor must have fresh feedback.
        `--no-telem`: at least one motor fresh (silent axes are allowed).
        """
        timestamps = np.asarray(self.motor.last_feedback_time, dtype=np.float64)
        if timestamps.shape != (len(MOTOR_IDS),):
            return False
        ages = time.monotonic() - timestamps
        fresh = (timestamps > 0.0) & (ages < TELEMETRY_TIMEOUT_S)
        if getattr(self.args, "no_telem", False):
            return bool(np.any(fresh))
        return bool(np.all(fresh))

    def _stale_motor_ids(self) -> list[int]:
        now = time.monotonic()
        stamps = np.asarray(self.motor.last_feedback_time, dtype=np.float64)
        stale: list[int] = []
        for mid, stamp in zip(MOTOR_IDS, stamps):
            if stamp <= 0.0 or now - float(stamp) >= TELEMETRY_TIMEOUT_S:
                stale.append(int(mid))
        return stale

    def _warn_missing_telem(self, context: str) -> None:
        stale = self._stale_motor_ids()
        if not stale:
            return
        ids = ", ".join(f"0x{mid:02x}" for mid in stale)
        print(
            f"\nWARNING ({context}): no/stale motor telemetry from [{ids}] "
            "(continuing because --no-telem).",
            flush=True,
        )

    def _wait_for_feedback(self, timeout_s: float = TELEMETRY_TIMEOUT_S) -> bool:
        deadline = time.monotonic() + timeout_s
        while time.monotonic() < deadline:
            self.motor.motion_control_once()
            if self._motor_feedback_fresh():
                return True
            time.sleep(0.02)
        return False

    def _temperature_trip(self) -> bool:
        motor_hot = bool(np.any(np.asarray(self.motor.motor_temp) >= self.args.motor_temp_limit))
        drive_hot = bool(np.any(np.asarray(self.motor.drive_temp) >= self.args.drive_temp_limit))
        return motor_hot or drive_hot

    def _temperature_cooled(self) -> bool:
        return bool(
            np.all(
                np.asarray(self.motor.motor_temp)
                < self.args.motor_temp_limit - TEMP_HYSTERESIS_C
            )
            and np.all(
                np.asarray(self.motor.drive_temp)
                < self.args.drive_temp_limit - TEMP_HYSTERESIS_C
            )
        )

    def _trip_thermal_lock(self) -> None:
        if not self.thermal_lock:
            print(
                "\nTHERMAL STOP: motors disabled "
                f"(motor={self.motor.motor_temp}, drive={self.motor.drive_temp})."
            )
        self.motor.disable()
        self.armed = False
        self.thermal_lock = True

    def _poll_thermal_lock(self) -> None:
        now = time.monotonic()
        if now - self.last_thermal_poll < 1.0:
            return
        self.last_thermal_poll = now
        self.motor.disable()
        time.sleep(0.03)
        if self._motor_feedback_fresh() and self._temperature_cooled():
            self.thermal_lock = False
            print("\nTemperatures recovered. Send a new movement command to re-arm.")

    def read_imu(self) -> ImuState:
        counter = int(self.imu.counter)
        now = time.monotonic()
        if counter != self.last_imu_counter:
            self.last_imu_counter = counter
            self.last_imu_update = now
        if now - self.last_imu_update > TELEMETRY_TIMEOUT_S:
            raise RuntimeError("IMU telemetry is stale")
        return ImuState.from_device(self.imu, self.yaw_reference_rad)

    @property
    def yaw_reference_deg(self) -> float:
        return math.degrees(self.yaw_reference_rad)

    def rotate_yaw_reference(self, delta_deg: float) -> None:
        """Turn the command frame about world +Z, so W/A/S/D drive somewhere else.

        Only the command/observation frame moves: slider calibration, joint targets and
        the travel clamps are untouched, so this is safe to do while armed.
        """
        self.yaw_reference_rad = wrap_to_pi(
            self.yaw_reference_rad + math.radians(delta_deg)
        )
        print(
            f"\nYaw reference {delta_deg:+.0f} deg -> W now drives "
            f"{self.yaw_reference_deg:+.1f} deg in the calibrated IMU frame "
            f"(--yaw-offset-deg {self.yaw_reference_deg:.1f})"
        )
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

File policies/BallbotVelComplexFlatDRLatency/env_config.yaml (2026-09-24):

simulation:
  timestep: 0.005
  decimation: 4
  control_freq: 50.0
  gravity_compensation:
  - shoulder
  - elbow
  - wrist
default_pose:
  root_position:
  - 0.0
  - 0.0
  - 0.194
  joint_pos:
    base_link_Slider-5: 0.0
    base_link_Slider-6: 0.0
    base_link_Slider-7: 0.0
observation:
  actor:
    angular_velocity:
      history_length: 3
      flatten_history_dim: false
      scale: null
      clip: null
      delay_hold_prob: 0.0
      delay_max_lag: 2
      delay_min_lag: 0
      term_dim: 3
      params: {}
    commands_xy:
      history_length: 3
      flatten_history_dim: false
      scale: null
      clip: null
      delay_hold_prob: 0.0
      delay_max_lag: 0
      delay_min_lag: 0
      term_dim: 2
      params: {}
    dofPosition:
      history_length: 3
      flatten_history_dim: false
      scale: null
      clip: null
      delay_hold_prob: 0.0
      delay_max_lag: 2
      delay_min_lag: 0
      term_dim: 3
      params: {}
    dofVelocity:
      history_length: 3
      flatten_history_dim: false
      scale: null
      clip: null
      delay_hold_prob: 0.0
      delay_max_lag: 2
      delay_min_lag: 0
      term_dim: 3
      params: {}
    actions:
      history_length: 3
      flatten_history_dim: false
      scale: null
      clip: null
      delay_hold_prob: 0.0
      delay_max_lag: 0
      delay_min_lag: 0
      term_dim: 3
      params: {}
    base_rotation_matrix:
      history_length: 3
      flatten_history_dim: false
      scale: null
      clip: null
      delay_hold_prob: 0.0
      delay_max_lag: 2
      delay_min_lag: 0
      term_dim: 9
      params: {}
  critic:
    angular_velocity:
      history_length: 3
      flatten_history_dim: true
      scale: null
      clip: null
      delay_hold_prob: 0.0
      delay_max_lag: 2
      delay_min_lag: 0
      term_dim: 3
      params: {}
    commands_xy:
      history_length: 3
      flatten_history_dim: true
      scale: null
      clip: null
      delay_hold_prob: 0.0
      delay_max_lag: 0
      delay_min_lag: 0
      term_dim: 2
      params: {}
    dofPosition:
      history_length: 3
      flatten_history_dim: true
      scale: null
      clip: null
      delay_hold_prob: 0.0
      delay_max_lag: 2
      delay_min_lag: 0
      term_dim: 3
      params: {}
    dofVelocity:
      history_length: 3
      flatten_history_dim: true
      scale: null
      clip: null
      delay_hold_prob: 0.0
      delay_max_lag: 2
      delay_min_lag: 0
      term_dim: 3
      params: {}
    actions:
      history_length: 3
      flatten_history_dim: true
      scale: null
      clip: null
      delay_hold_prob: 0.0
      delay_max_lag: 0
      delay_min_lag: 0
      term_dim: 3
      params: {}
    base_rotation_matrix:
      history_length: 3
      flatten_history_dim: true
      scale: null
      clip: null
      delay_hold_prob: 0.0
      delay_max_lag: 2
      delay_min_lag: 0
      term_dim: 9
      params: {}
  estimator_target:
    base_lin_vel:
      history_length: 0
      flatten_history_dim: true
      scale: null
      clip: null
      delay_hold_prob: 0.0
      delay_max_lag: 0
      delay_min_lag: 0
      term_dim: 3
      params: {}
action:
  dim: 3
  low_pass_alpha: 1.0
  clip_actions: 1.0
  controlled_joints:
  - base_link_Slider-5
  - base_link_Slider-6
  - base_link_Slider-7
actuators:
- joints:
  - base_link_Slider-\d+
  kp: 78956.83520871487
  kd: 3947.8417604357433
  action_scale: 0.106
  effort_limit: 31.41592653589793
  armature: 0.03136560278666198
  joint_damping: 0.0
  joint_friction: 0.2
foot_bodies: []
obs_dim: 23
policy_obs_group: actor
has_velocity_estimator: true

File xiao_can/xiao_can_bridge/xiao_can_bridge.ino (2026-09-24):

#include "Can_driver.h"

const char *BRIDGE_VERSION = "BALLBOT_XIAO_BRIDGE_V3";

String inputBuffer = "";

void setup() {
  // Configure onboard RGB LED pins
  pinMode(LED_RED, OUTPUT);
  pinMode(LED_GREEN, OUTPUT);
  pinMode(LED_BLUE, OUTPUT);

  // Turn all LEDs off initially (active-low logic)
  digitalWrite(LED_RED, HIGH);
  digitalWrite(LED_GREEN, HIGH);
  digitalWrite(LED_BLUE, HIGH);

  // Blue on startup
  digitalWrite(LED_BLUE, LOW);

  Serial.begin(115200);

  // Wait up to 3 seconds for Serial (USB CDC) host connection, but proceed
  // anyway for headless
  unsigned long startWait = millis();
  while (!Serial && (millis() - startWait < 3000)) {
    delay(10);
  }
  delay(2000);

  // Failure Pattern 2: CAN initialization failed (Blink Red 2 times, pause)
  if (!init_can()) {
    digitalWrite(LED_BLUE, HIGH); // Turn off startup blue
    if (Serial)
      Serial.println("Error Initializing MCP2515...");
    while (1) {
      digitalWrite(LED_RED, LOW);
      delay(200);
      digitalWrite(LED_RED, HIGH);
      delay(200);
      digitalWrite(LED_RED, LOW);
      delay(200);
      digitalWrite(LED_RED, HIGH);
      delay(1000);
    }
  }

  // Running correctly: Turn off blue/red, turn on green
  digitalWrite(LED_BLUE, HIGH);
  digitalWrite(LED_RED, HIGH);
  digitalWrite(LED_GREEN, LOW);

  if (Serial)
    Serial.println("CAN Init OK at 1Mbps");
  if (Serial)
    Serial.println(BRIDGE_VERSION);
  inputBuffer.reserve(64);

  // Clear faults, then disable, on each motor. No homing and no encoder zeroing
  // here: the host does both (ballbot_terminal.py home_and_center, set_pos_zero).
  // Must match MOTOR_IDS in src/ballbot_runtime.py.
  const uint8_t motors[] = {0x08, 0x07, 0x06};
  byte clear_buf[8] = {0xFF, 0xFF, 0xFF, 0xFF, 0xFF, 0xFF, 0xFF, 0xFB};
  byte disable_buf[8] = {0xFF, 0xFF, 0xFF, 0xFF, 0xFF, 0xFF, 0xFF, 0xFD};
  delay(100);
  for (uint8_t motor_id : motors) {
    send_can_message(0x100 | motor_id, 8, clear_buf);
    delay(2);
  }
  delay(10);
  for (uint8_t motor_id : motors) {
    send_can_message(0x100 | motor_id, 8, disable_buf);
    delay(2);
  }
}

void processSerialCommand(String line) {
  line.trim();
  if (line == "V") {
    Serial.print("V:");
    Serial.println(BRIDGE_VERSION);
    return;
  }
  // Bench-only bitrate probe; no host script sends it. "B:<kbps>" (1000, 500 or
  // 250) re-initialises the MCP2515 at that rate and sends one disable frame to
  // CAN ID 0x102 (motor 0x02, which is not on this robot). The bridge stays at
  // that rate until it is reset.
  if (line.startsWith("B:")) {
    int kbps = line.substring(2).toInt();
    byte speed = kbps == 1000 ? CAN_1000KBPS
                 : kbps == 500 ? CAN_500KBPS
                 : kbps == 250 ? CAN_250KBPS
                               : 0;
    bool initialized = speed != 0 && init_can(speed);
    byte tx_status = 0xFF;
    byte error_status = 0xFF;
    if (initialized) {
      byte disable_buf[8] = {0xFF, 0xFF, 0xFF, 0xFF,
                             0xFF, 0xFF, 0xFF, 0xFD};
      delay(100);
      tx_status = send_can_message_status(0x102, 8, disable_buf);
      error_status = can_error_status();
    }
    Serial.print("B:");
    Serial.print(kbps);
    Serial.print(":");
    Serial.print(initialized ? 1 : 0);
    Serial.print(":");
    Serial.print(tx_status);
    Serial.print(":");
    Serial.println(error_status);
    return;
  }
  if (line.startsWith("S:") || line.startsWith("T:")) {
    bool report_status = line.startsWith("T:");
    int idx1 = line.indexOf(':', 2);
    int idx2 = line.indexOf(':', idx1 + 1);
    if (idx1 != -1 && idx2 != -1) {
      unsigned long id = strtoul(line.substring(2, idx1).c_str(), NULL, 16);
      int dlc = line.substring(idx1 + 1, idx2).toInt();
      String hex = line.substring(idx2 + 1);
      byte buf[8] = {0};
      for (int i = 0; i < dlc && i < 8; i++) {
        String byteHex = hex.substring(i * 2, i * 2 + 2);
        buf[i] = strtoul(byteHex.c_str(), NULL, 16);
      }
      byte tx_status = send_can_message_status(id, dlc, buf);
      if (report_status) {
        Serial.print("T:");
        Serial.print(id, HEX);
        Serial.print(":");
        Serial.print(tx_status);
        Serial.print(":");
        Serial.println(can_error_status());
      }
    }
  }
}

void loop() {
  // 1. Forward CAN packets to Serial
  unsigned long id;
  byte len = 0;
  byte buf[8];
  if (read_can_message(id, len, buf)) {
    if (Serial) {
      Serial.print("R:");
      Serial.print(id, HEX);
      Serial.print(":");
      Serial.print(len);
      Serial.print(":");
      for (int i = 0; i < len; i++) {
        if (buf[i] < 16)
          Serial.print("0");
        Serial.print(buf[i], HEX);
      }
      Serial.println();
    }
  }

  // 2. Forward Serial packets to CAN (Non-blocking byte-by-byte reader)
  while (Serial && Serial.available() > 0) {
    char c = Serial.read();
    if (c == '\n') {
      processSerialCommand(inputBuffer);
      inputBuffer = "";
    } else if (c != '\r') {
      inputBuffer += c;
    }
  }
}

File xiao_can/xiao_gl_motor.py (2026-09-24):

"""
CubeMars GL40 II motor controller through the Seeed XIAO USB-serial CAN bridge.

The bridge firmware is xiao_can/xiao_can_bridge/xiao_can_bridge.ino. When the port
opens, the bridge must report BRIDGE_VERSION, at boot or in reply to a "V" query
(see docs/FLASH_XIAO.md).
"""

import time
import threading
import numpy as np
import serial
from serial.tools import list_ports
import struct
import glob
import sys

GL40 = 40
GL_MODE_MIT = 0
GL_MODE_POS_VEL = 1
GL_MODE_VEL = 2
BRIDGE_VERSION = "BALLBOT_XIAO_BRIDGE_V3"

# Scaling Limits (must match the GL40 II datasheet)
P_MIN, P_MAX = -12.5, 12.5
V_MIN, V_MAX = -120.0, 120.0
T_MIN, T_MAX = -10.0, 10.0

# Universal CAN command payloads (byte 7 determines the command)
CMD_CLEAR_ERRORS    = b"\xFF\xFF\xFF\xFF\xFF\xFF\xFF\xFB"
CMD_ENTER_CONTROL   = b"\xFF\xFF\xFF\xFF\xFF\xFF\xFF\xFC"
CMD_EXIT_CONTROL    = b"\xFF\xFF\xFF\xFF\xFF\xFF\xFF\xFD"
CMD_SET_ZERO_POS    = b"\xFF\xFF\xFF\xFF\xFF\xFF\xFF\xFE"

# CubeMars GL II feedback nibble (data[0] >> 4). 0/1 are status; >=8 are faults.
GL40_STATUS_NAMES = {
    0: "disable",
    1: "enable",
    8: "over_voltage",
    9: "under_voltage",
    10: "over_current",
    11: "mos_over_temp",
    12: "motor_over_temp",
    13: "comm_loss",
    14: "overload",
}
GL40_FAULT_CODES = frozenset({8, 9, 10, 11, 12, 13, 14})


def gl40_status_name(code: int) -> str:
    return GL40_STATUS_NAMES.get(int(code), f"unknown_{int(code)}")


def _get_can_id(motor_id, mode):
    """Encode mode into the CAN arbitration ID: (mode << 8) | motor_id."""
    return (mode << 8) | (motor_id & 0xFF)


def uint_to_float(x_int, x_min, x_max, bits):
    span = x_max - x_min
    return float(x_int) * span / float((1 << bits) - 1) + x_min
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

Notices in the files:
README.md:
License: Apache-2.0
